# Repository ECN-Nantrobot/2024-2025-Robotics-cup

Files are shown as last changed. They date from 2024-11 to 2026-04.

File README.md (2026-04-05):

# 🤖 2025 Eurobot France Robot from EC NATES Team

<p align="center">
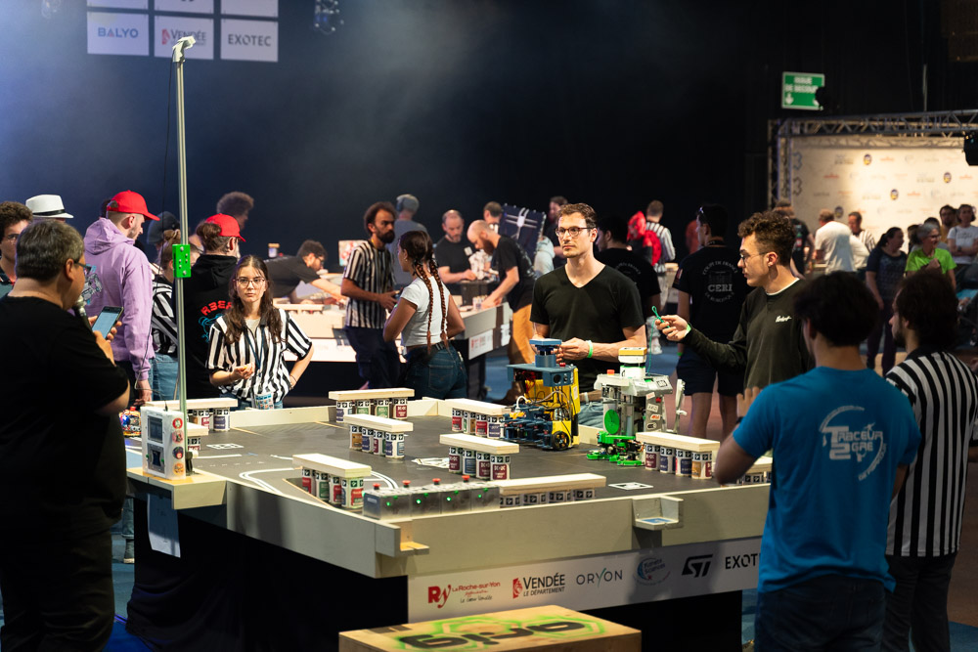
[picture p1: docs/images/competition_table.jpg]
Eurobot competition table

</p>

This repository contains the software used for our **Eurobot France 2025** mobile robot.

Competition objective (software side):
- move safely on the table,
- pick up cans,
- move them to scoring zones,
- and stack them with a wooden plank,
while coordinating high-level autonomy (Raspberry Pi + ROS2) and low-level actuation (ESP32).

---

## ⚡ Quick Summary (TL;DR)

- This repository is the full competition software stack for our **Eurobot France 2025** robot, split between high-level **ROS2** autonomy on the **Raspberry Pi** and real-time actuator control on the **ESP32**.
- The robot mission flow is: navigate the table, pick cans, transport them, and stack them according to ordered match goals defined in YAML strategies (blue/yellow team variants).
- On the ROS2 side, `main_node` coordinates mission sequencing, ESP synchronization, and runtime state progression, while `laser_to_pointcloud_node` converts LiDAR scans into map-frame pointcloud data.
- Perception updates an OpenCV-backed maze/occupancy representation; close LiDAR points are used for collision-aware behavior and safety reactions during execution.
- The planning stack includes A* path search and Elastic Band smoothing/optimization modules to turn discrete routes into smoother, obstacle-aware motion references.
- Raspberry Pi and ESP32 communicate over serial (`/dev/esp32`) with command/ack/state messages so high-level decisions and low-level actions stay synchronized.
- Deployment supports both manual ROS launching and automatic startup with `one_go.service`; additional operator setup/troubleshooting notes are collected in `noted.md`.
- The detailed sections below explain architecture layers, data flow, planning internals, state-machine behavior, build/run steps, and autostart operations.

---

## 🎥 Competition links

- **YouTube live stream (competition):** https://www.youtube.com/watch?v=Y8KNj2Q6Nss
- **Official Eurobot 2025 page:** https://www.eurobot.org/eurobot-contest/eurobot-2025/

---

## Photos

<p align="center">
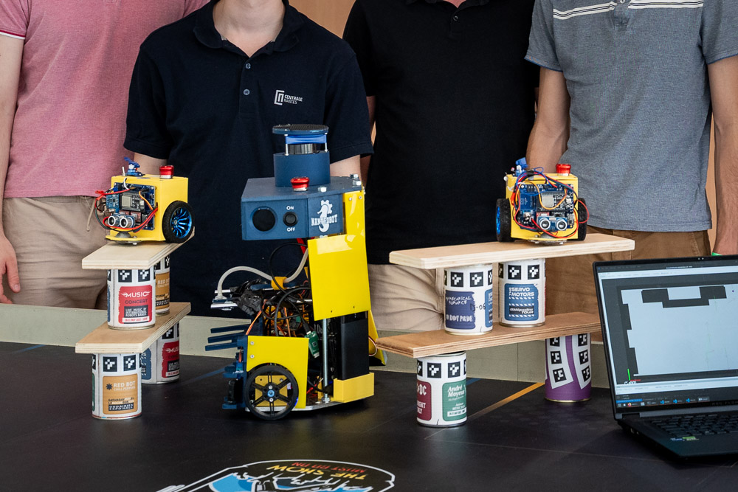
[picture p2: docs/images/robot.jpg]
Team with robot at competition
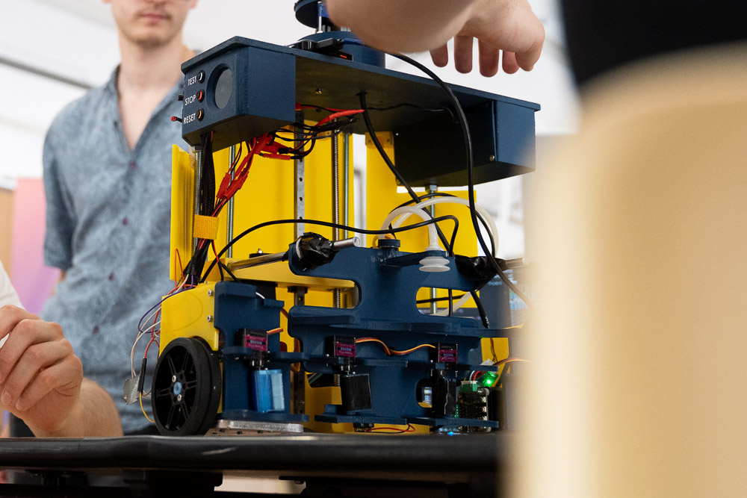
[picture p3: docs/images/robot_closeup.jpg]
Robot close-up
   
  <br>
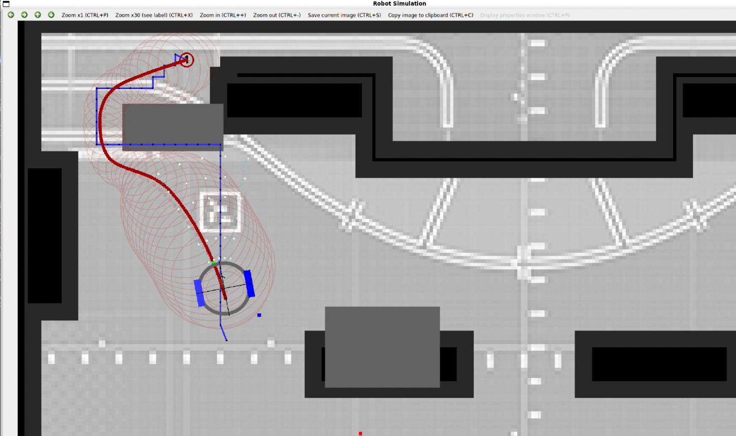
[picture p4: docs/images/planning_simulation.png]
Planning and simulation view
  
</p>

---

## 1) System architecture (code architecture, not just file tree)

The software is designed as a **layered robotics stack**.

## 🎯 Layer A — Match strategy and mission sequencing (ROS2)
Responsibility 📌:
- load team strategy (blue/yellow),
- keep an ordered goal list,
- advance mission state machine,
- synchronize with ESP (start/reset/ack/state).

Core behavior ⚡:
- `main_node` loads YAML goals and robot tuning parameters.
- It sends high-level goals and PID/speed values over serial.
- It tracks progress and decides when to move to the next objective.

---

## Layer B — Environment modeling and local world update (ROS2 + OpenCV + PointCloud)
Responsibility 📌:
- convert raw LiDAR scans into useful obstacle information,
- maintain occupancy/maze image representation,
- mark dangerous/blocked regions around detected clusters.

Core behavior ⚡:
1. LiDAR `/scan` is projected to PointCloud2 and transformed into map frame.
2. Point cloud is filtered and clustered.
3. Cluster centers are smoothed over time.
4. Circular obstacle areas are written into the map image (OpenCV-backed maze).

This is what gives the planner a live, robot-centric table understanding.

---

## Layer C — Path planning and path shaping (A* + Elastic Bands)
Responsibility 📌:
- compute traversable path from robot to current goal,
- refine the path for smooth and obstacle-aware motion.

### A* planner (global/discrete path)
- The codebase includes a generic templated **A\*** implementation.
- It builds a search tree with open/closed sets and returns an ordered path.
- Utility functions exist to save/load A* paths for debugging.

### Elastic Bands optimizer (path smoothing/optimization)
- The codebase also contains an **Elastic Band** optimizer:
  - path resampling (`resizePath`),
  - spring force term (path smoothness),
  - repulsive force term (obstacle clearance),
  - corridor checks and obstacle repulsion,
  - Gaussian smoothing for final trajectory quality.
- It queries obstacle distance using the maze distance transform for fast collision pressure.

> Important: in the current `main.cpp`, parts of A* and Elastic Band usage are present but some calls are commented while mission logic still runs via goal sequencing and safety/obstacle updates.

---

## Layer D — Motion command bridging (ROS2 ↔ ESP32 serial protocol)
Responsibility 📌:
- convert ROS-level goals/tuning into compact serial commands,
- receive acknowledgements and finite state updates from ESP.

Core behavior ⚡:
- ROS sends messages such as:
  - `GOALS:...`
  - speed/PID command payloads,
- ROS parses incoming messages such as:
  - `ACK:...`
  - `RESET`
  - state updates.

This bridge is the contract between navigation intelligence and hardware execution.

Communication behavior in practice:
- The Raspberry Pi opens the ESP link on `/dev/esp32` and waits for startup synchronization.
- During startup, ROS waits for trigger/state messages (including start/team-color flow) before mission execution.
- ROS then sends:
  - speed and PID tuning,
  - the ordered mission goals,
  - additional control messages tied to match progress.
- ESP acknowledges received commands and reports current execution state back.
- If ROS receives a reset/state change, the mission controller in `main_node` can re-initialize and safely re-sync.

---

## Layer E — Real-time low-level control (ESP32 firmware)
Responsibility 📌:
- deterministic wheel/servo/pump/stacking control,
- panel/safety handling,
- sensor and actuator timing not suitable for Linux user-space jitter.

Core behavior ⚡:
- Execute movement primitives and mechanism sequences.
- Handle pickup/stacking actions.
- Return status to ROS so high-level state machine can continue.

---

## Layer F — Launch/runtime orchestration
Responsibility 📌:
- bring up the complete runtime graph reliably.

Core behavior ⚡:
- ROS launch starts TF/static transform, robot state publisher, LiDAR driver, pointcloud transform, and main autonomy node.
- systemd service can autostart all of this on Raspberry Pi boot.

---

## 🔄 2) Data flow between components

End-to-end loop:
1. **LiDAR driver** publishes `/scan`.
2. **`laser_to_pointcloud_node`** transforms to `/pointcloud` in map frame.
3. **`main_node`** updates the OpenCV maze from clustered points.
4. **LiDAR-based collision detection** marks too-close obstacle points and can trigger emergency/safety behavior in the control loop.
5. Planner/mission logic chooses next movement objective.
6. ROS sends goal/tuning messages to ESP32 via serial (`/dev/esp32`).
7. ESP32 executes motors/servos/pump/stacking and reports state.
8. ROS advances mission state and repeats until final objective.

---

## 🧠 3) ROS2 package functionality details (`robonav`)

### 3.1 Main autonomy node
`main_node` integrates:
- serial handshake with ESP,
- team color + start synchronization,
- loading strategy YAML (`goals_blue_final.yaml` / `goals_yellow_final.yaml`),
- publication of odom/path/goals visualization topics,
- pointcloud-based obstacle map updates,
- LiDAR-based close-obstacle filtering for emergency/collision-aware behavior,
- mission progression logic.

State-machine perspective of the main loop:
- **Init / sync state**: open serial, wait for ESP availability, wait for START + team-color context.
- **Configuration state**: load YAML strategy, apply speed/PID, send goals and config payloads to ESP.
- **Run state**: execute mission step-by-step while continuously processing LiDAR-derived obstacle updates.
- **Transition state**: when a goal/action is completed and acknowledged, advance to next strategic step.
- **Safety/reset state**: if reset/emergency conditions are detected, stop or reinitialize and return to a safe synchronization phase.

This state-machine behavior is what coordinates high-level ROS mission logic with low-level ESP execution confirmations.

### 3.2 LiDAR transform node
`laser_to_pointcloud_node`:
- subscribes to `/scan`,
- projects scan to PointCloud2,
- transforms cloud into map frame via TF2,
- publishes `/pointcloud` for planning/perception pipeline.

### 3.3 Map model with OpenCV (`Maze`)
The Maze abstraction provides:
- occupancy image manipulation,
- obstacle rendering (with borders/safety margins),
- precomputed distance transform,
- fast `getDistanceToObstacle()` lookup used by path optimization forces.

This OpenCV map is central to both collision logic and path quality.

### 3.4 A* planning module
The A* module supports:
- reusable generic node-based search,
- heuristic + g/f cost handling,
- parent tree reconstruction of final path,
- optional path persistence to files for debugging and replay.

### 3.5 Elastic Bands module
The Elastic Band module supports:
- iterative path optimization,
- spring/repulsive forces,
- adaptive spacing and corridor correction,
- smoothing using Gaussian kernel,
- optional visualization utilities.

Use case:
- A* gives a valid path,
- Elastic Band transforms it into smoother, safer motion references.

### 3.6 Strategy and configuration
Competition behavior is configured through YAML:
- wheel geometry,
- speed/PID defaults,
- ordered goals for each team color,
- obstacle templates.

---

## ⚙️ 4) ESP32 firmware functionality (control architecture)

The ESP firmware acts as a **real-time execution controller**.

Major functional blocks:
- drivetrain motion control,
- servo control,
- pump control,
- stacking sequence management,
- power monitoring,
- control panel / emergency and safety handling,
- command parser for ROS serial protocol.

Design intent:
- ROS does “what to do next”,
- ESP does “how to move and actuate now”.

---

## 🛠️ 5) Technologies used

### Raspberry Pi / ROS side
- ROS 2 Humble
- C++17
- Python ROS launch
- OpenCV (map and image operations)
- PCL + laser_geometry + TF2 (pointcloud and transforms)
- yaml-cpp (strategy/config loading)
- systemd (autostart)

### ESP side
- PlatformIO
- Arduino framework (ESP32)
- AccelStepper, ContinuousStepper, TFT_eSPI, INA219, PWM servo driver

---

## ⏱️ 6) Runtime sequence during a match

1. Boot RPi and ESP.
2. Launch ROS graph (manual or systemd).
3. Wait for ESP start/team-color synchronization.
4. Load corresponding team goals.
5. Start mission loop:
   - perceive obstacles,
   - update map,
   - plan/shape motion,
   - send commands,
   - execute pickup/stacking actions,
   - verify state and continue.
6. End at final strategic goal.

---

## 🚀 7) Build and run

### 🧪 ROS2 workspace (RPi)
```bash
colcon build --symlink-install
source install/setup.bash
ros2 launch robonav launch.launch.py
```

### 🔋 ESP firmware
- Open `Firmware/` with PlatformIO.
- Build and upload to ESP32.
- Ensure serial mapping is correct (`/dev/esp32` expected on RPi side).

---

## 🔁 8) Autostart (RPi)
Use the provided service assets to launch on boot:
- `src/robonav/autostart/one_go.sh`
- `src/robonav/autostart/one_go.service`

Then monitor:
```bash
journalctl -u one_go.service -f
```

---

## 📝 9) Practical operations notes

- Always confirm team color strategy file before match.
- Validate LiDAR and ESP serial devices after reboot.
- Keep ROS and firmware commits synchronized.
- Perform full mechanism test (pickup/stacking) before table deployment.

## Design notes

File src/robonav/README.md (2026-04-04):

# make it executable
chmod +x /home/pi/2024-2025-Robotics-cup/auto_start/one_go.sh

# make one_go.service symbolic so that you can call one_go.service with systemctl
sudo ln -s /home/pi/2024-2025-Robotics-cup/auto_start/one_go.service /etc/systemd/system

# enable and start one_go.service
sudo systemctl daemon-reload
sudo systemctl enable one_go.service
sudo systemctl start one_go.service
# now the launch will be start when the robot boots

# check if it's running
systemctl status one_go.service

Delete the service:
sudo systemctl stop one_go.service
sudo systemctl disable one_go.service
sudo rm /etc/systemd/system/one_go.service
sudo systemctl daemon-reload

# Live Logs output:
journalctl -u one_go.service -f

# Wifi: 
cd /etc/netplan/50-cloud-init.yaml
sudo netplan apply

# Launch Ros2
colcon build --symlink-install      in the 2024-2025..... 
source install/setup.bash
ros2 launch robonav launch.launch.py

ros2 run robonav led_test_node

I also made a file to auto detect the lidar and esp automatically and map the ports to /dev/esp32 and /dev/rplidar, so you can set teh port in platform.io extension to /dev/esp32

Safe start button needs to be on reset to upload, and press reset while it is building because sometimes it doesnt upload properly, and emergency need to be pressed

Starting and resetting the RPI takes a little bit long, I dont know, maybe because of the LED fucntion but not sure

The RPI Led is on GPIO pin 16

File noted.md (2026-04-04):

# Robot Operations Notes (Raspberry Pi + ROS2 + ESP32)

This file keeps practical setup and troubleshooting notes for running the robot on the Raspberry Pi.

---

## 1) Make autostart script executable

```bash
chmod +x /home/pi/2024-2025-Robotics-cup/auto_start/one_go.sh
```

---

## 2) Register `one_go.service` with systemd

Create a symbolic link so `systemctl` can manage the service:

```bash
sudo ln -s /home/pi/2024-2025-Robotics-cup/auto_start/one_go.service /etc/systemd/system
```

---

## 3) Enable and start service at boot

```bash
sudo systemctl daemon-reload
sudo systemctl enable one_go.service
sudo systemctl start one_go.service
```

After this, launch should start automatically when the robot boots.

Check status:

```bash
systemctl status one_go.service
```

---

## 4) Delete/remove the service

```bash
sudo systemctl stop one_go.service
sudo systemctl disable one_go.service
sudo rm /etc/systemd/system/one_go.service
sudo systemctl daemon-reload
```

---

## 5) Live logs

```bash
journalctl -u one_go.service -f
```

---

## 6) Wi-Fi/netplan

```bash
cd /etc/netplan/50-cloud-init.yaml
sudo netplan apply
```

---

## 7) Launch ROS2 manually

From repository root (`2024-2025-Robotics-cup`):

```bash
colcon build --symlink-install
source install/setup.bash
ros2 launch robonav launch.launch.py
```

Test node:

```bash
ros2 run robonav led_test_node
```

---

## 8) Device mapping note

A helper file/rule is used to auto-detect LiDAR and ESP and map ports to:
- `/dev/esp32`
- `/dev/rplidar`

In PlatformIO, you can set upload/monitor port to `/dev/esp32`.

---

## 9) ESP upload notes

- Keep **Safe Start button** on reset for upload.
- Press **reset while building/uploading** if upload fails (this happens sometimes).
- Emergency button needs to be pressed.

---

## 10) Startup/reset behavior note

- Raspberry Pi startup/reset can be a bit slow.
- Possible reason might be LED-related behavior (not confirmed).

Raspberry Pi LED pin used in this project:
- **GPIO 16**

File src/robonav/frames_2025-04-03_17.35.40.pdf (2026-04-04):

view_frames Result

Recorded at time: 1743701740.3750396

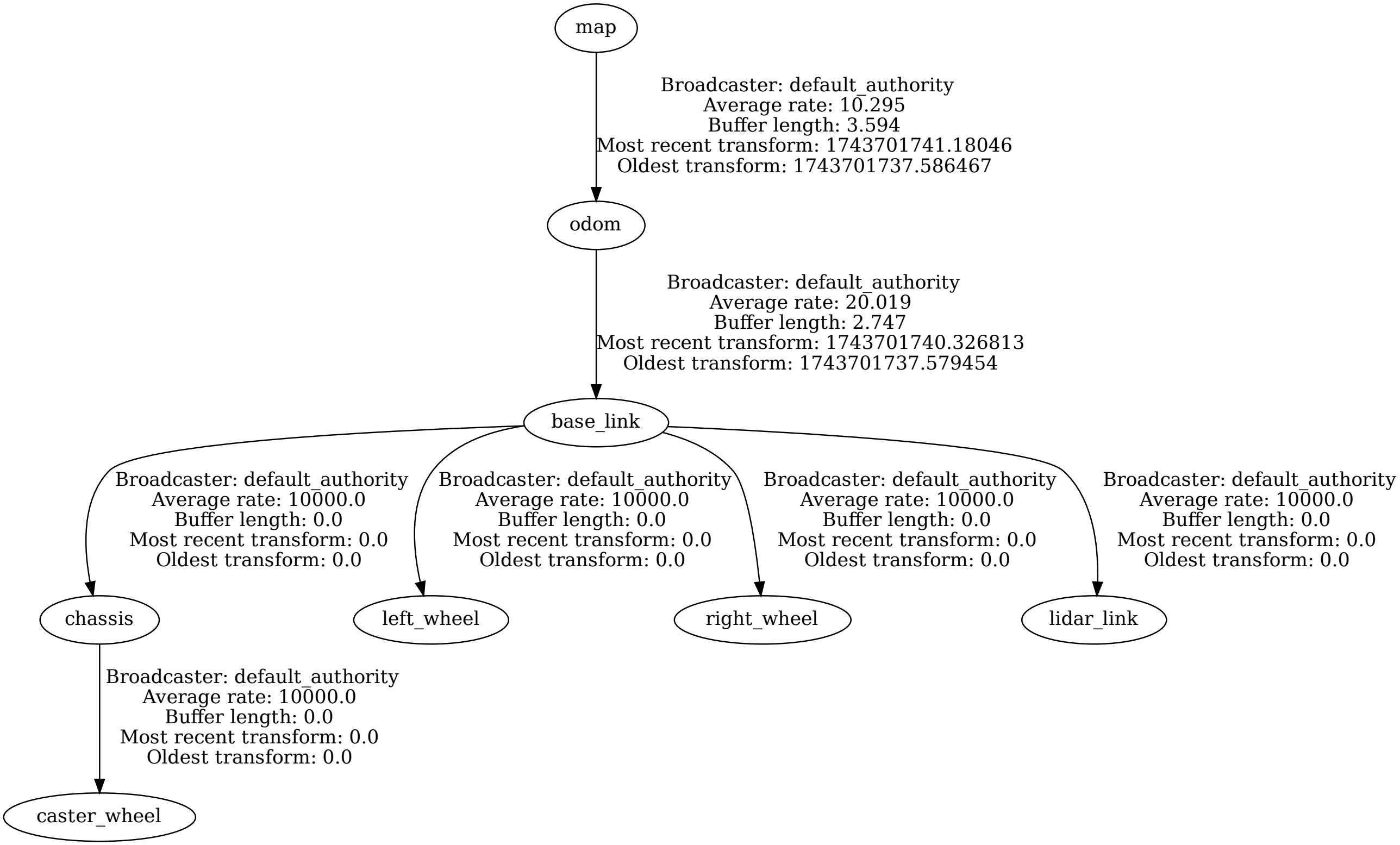
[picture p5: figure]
chassis; caster_wheel; Broadcaster: default_authority Average rate: 10000.0 Buffer length: 0.0 Most recent transform: 0.0 Oldest transform: 0.0; base_link; left_wheel; right_wheel; lidar_link; odom; Broadcaster: default_authority Average rate: 20.019 Buffer length: 2.747 Most recent transform: 1743701740.326813 Oldest transform: 1743701737.579454; map; Broadcaster: default_authority Average rate: 10.295 Buffer length: 3.594 Most recent transform: 1743701741.18046 Oldest transform: 1743701737.586467

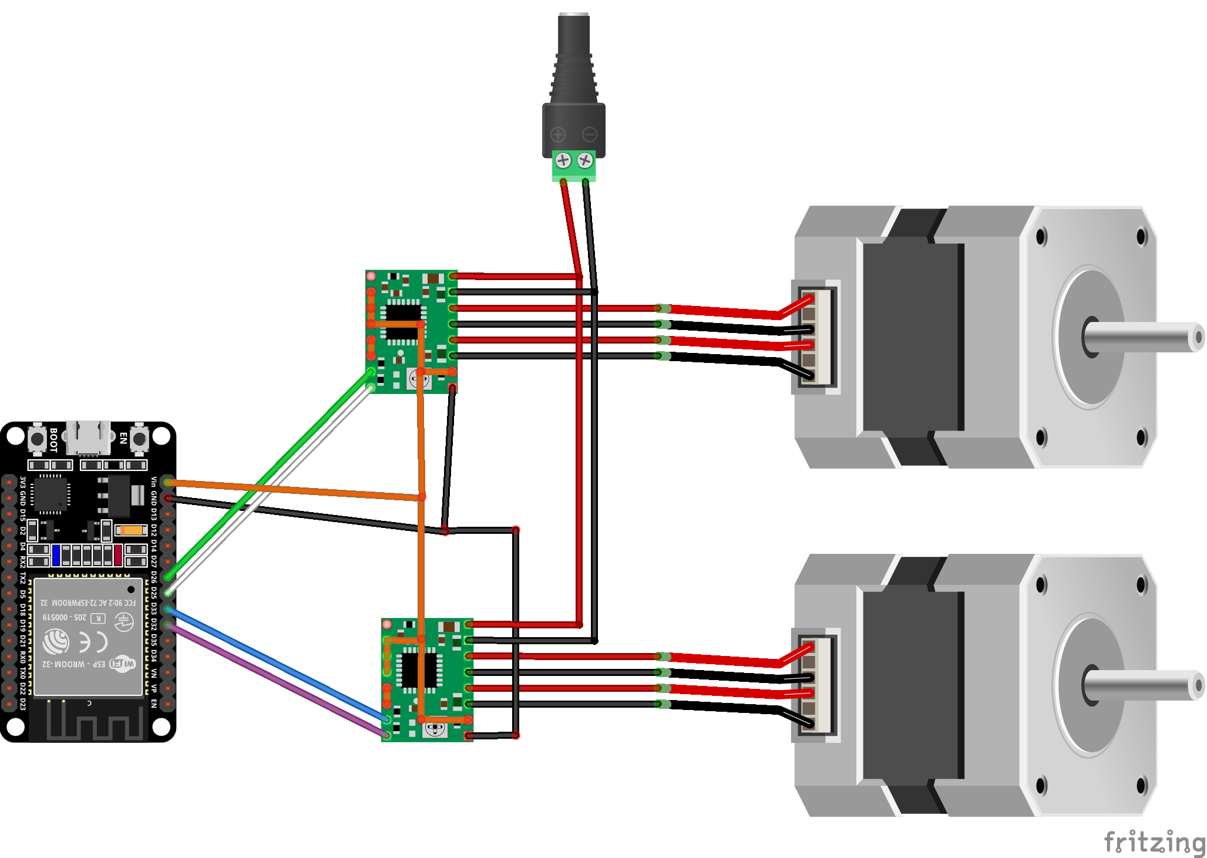
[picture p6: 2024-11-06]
Individual test/Mobile base/schematics esp32 2xNema17_bb.png

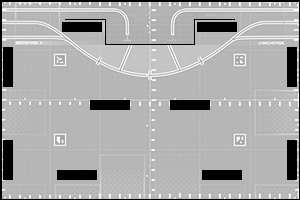
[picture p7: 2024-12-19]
src/robonav/maps/Eurobot_map_real_bw_10_p.png

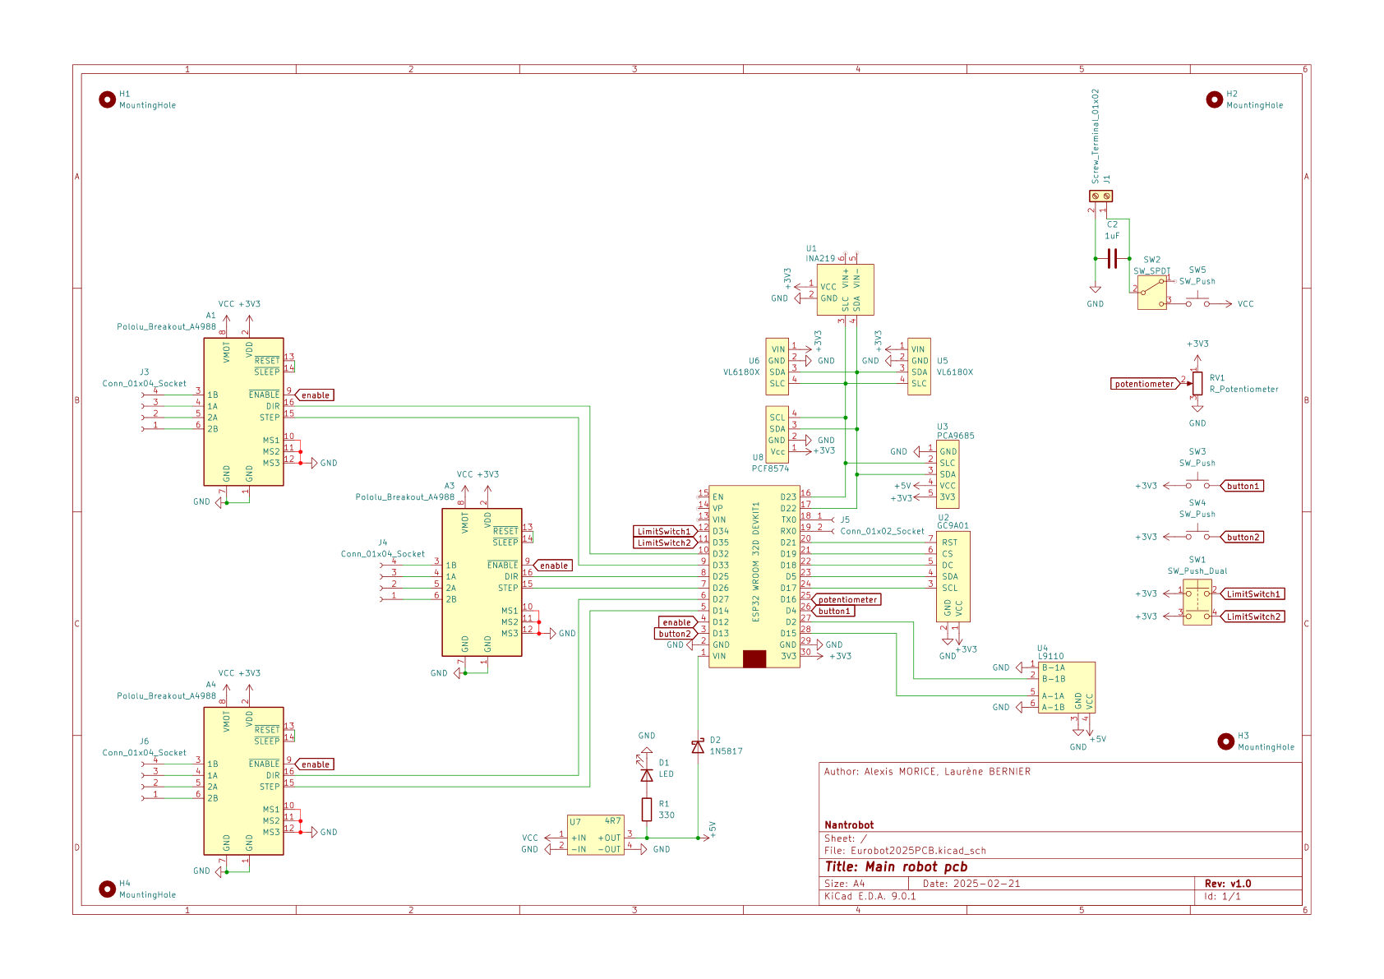
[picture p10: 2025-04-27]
Electrical/Version 2.0.png

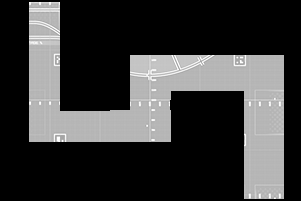
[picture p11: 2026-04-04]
src/robonav/maps/Eurobot_map_real_bw_10_p_interact.png

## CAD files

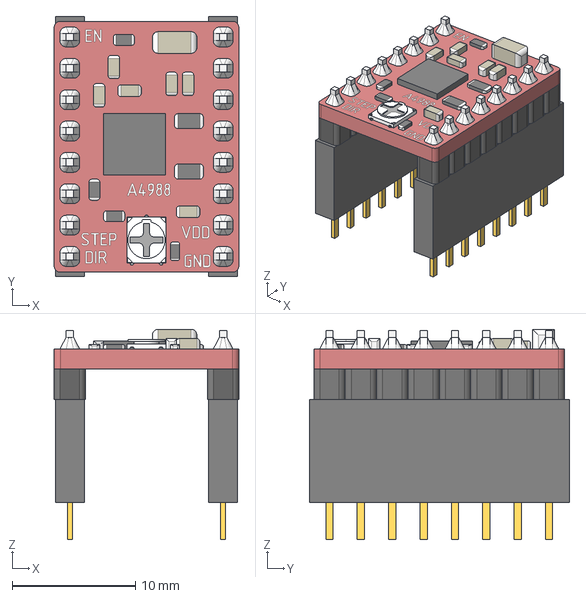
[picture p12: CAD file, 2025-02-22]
Electrical/Eurobot2025PCB/3D/A4988-Stepper-Driver-Socketed.stp
15.0 x 21.1 x 17.1 mm

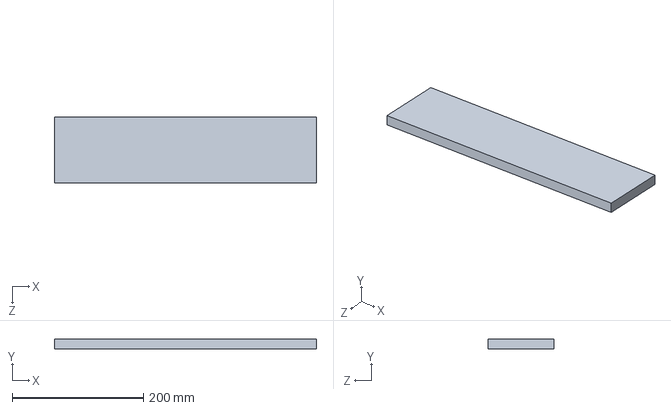
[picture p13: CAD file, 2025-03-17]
Mecanical/CAD/GAME ELEMENT/WOOD_PLATFORM.SLDPRT
400.0 x 15.0 x 100.0 mm

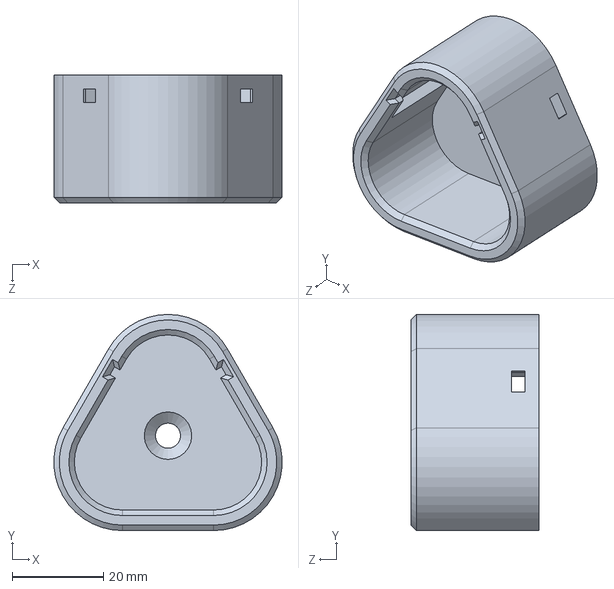
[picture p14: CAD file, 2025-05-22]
Mecanical/CAD/MOBILE BASE/BATTERY_HOLDER.SLDPRT
49.9 x 47.3 x 28.0 mm

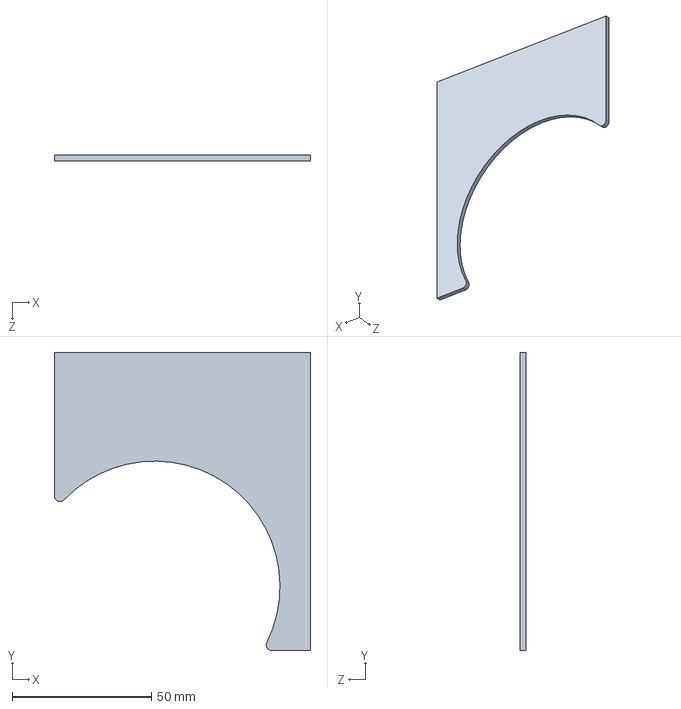
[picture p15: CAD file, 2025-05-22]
Mecanical/CAD/MOBILE BASE/Carter/motor_panel.SLDPRT
92.0 x 107.0 x 2.00 mm

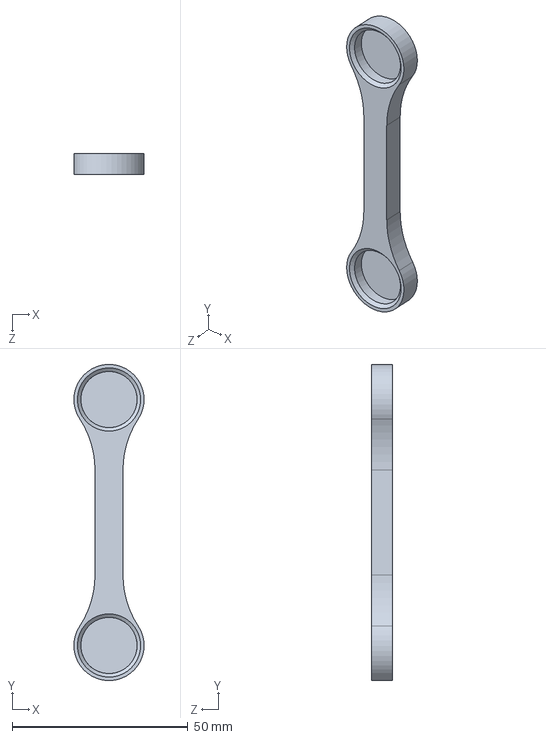
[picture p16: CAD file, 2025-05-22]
Mecanical/CAD/STACKING/Arm2.SLDPRT
20.0 x 89.9 x 6.00 mm

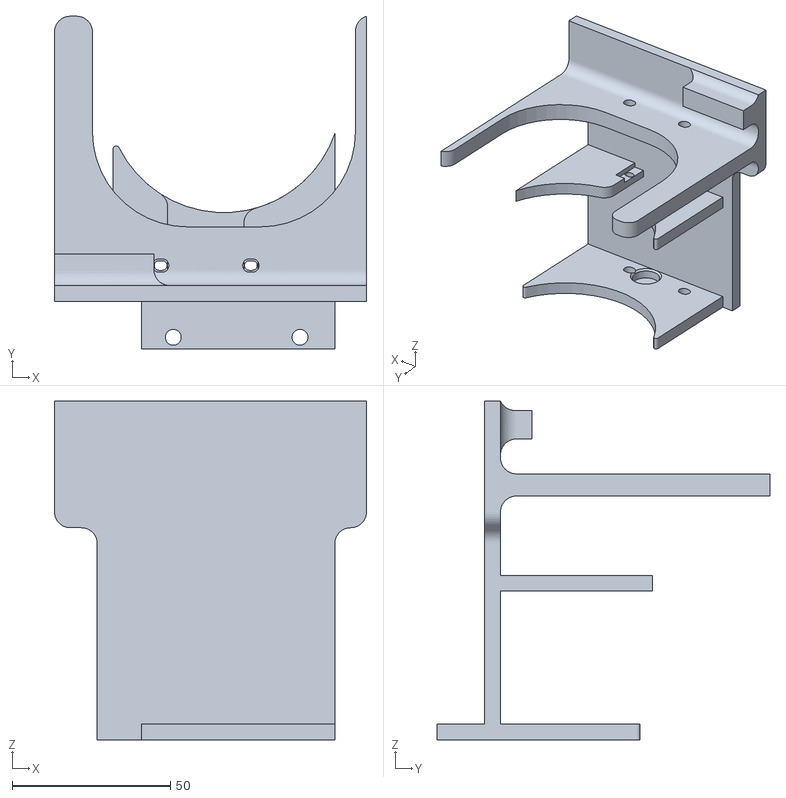
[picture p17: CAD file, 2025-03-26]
Mecanical/FRONT_ACTUATOR_SIDE.STL
98.5 x 105.0 x 107.0

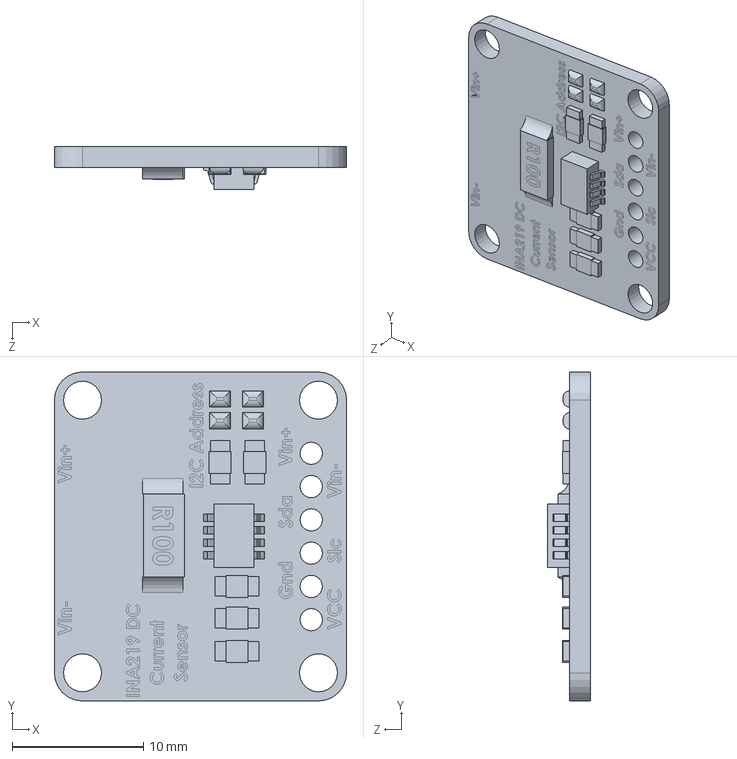
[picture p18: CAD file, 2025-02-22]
Electrical/Eurobot2025PCB/3D/INA219.SLDPRT
22.3 x 25.1 x 3.30 mm

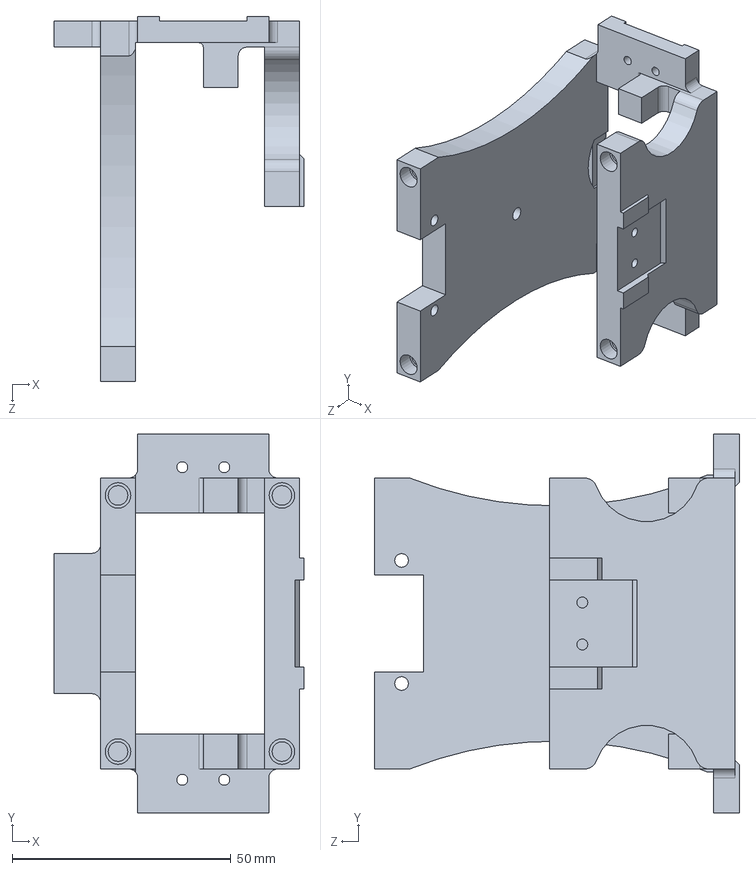
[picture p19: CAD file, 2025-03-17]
Mecanical/CAD/BANNER/MOVING_FRAME.SLDPRT
57.1 x 86.6 x 83.5 mm

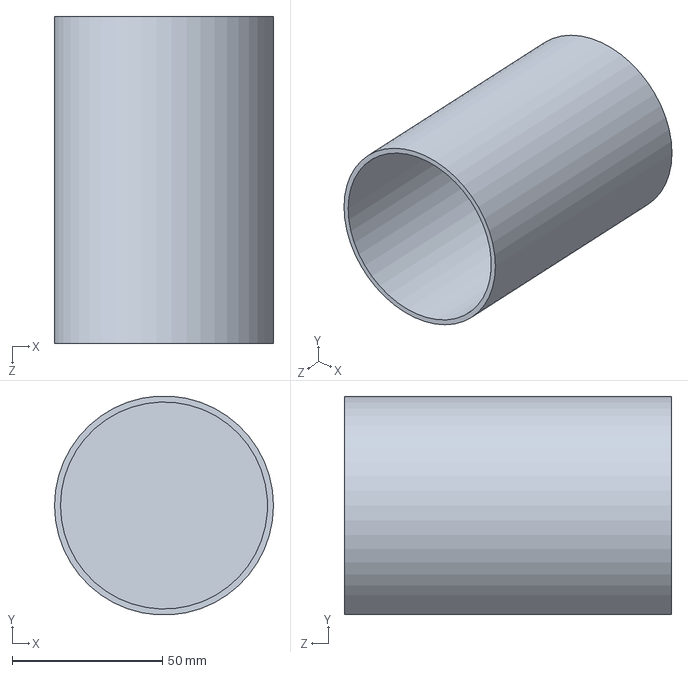
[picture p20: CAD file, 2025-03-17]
Mecanical/CAD/GAME ELEMENT/TIN_CAN.SLDPRT
73.0 x 72.8 x 109.0 mm

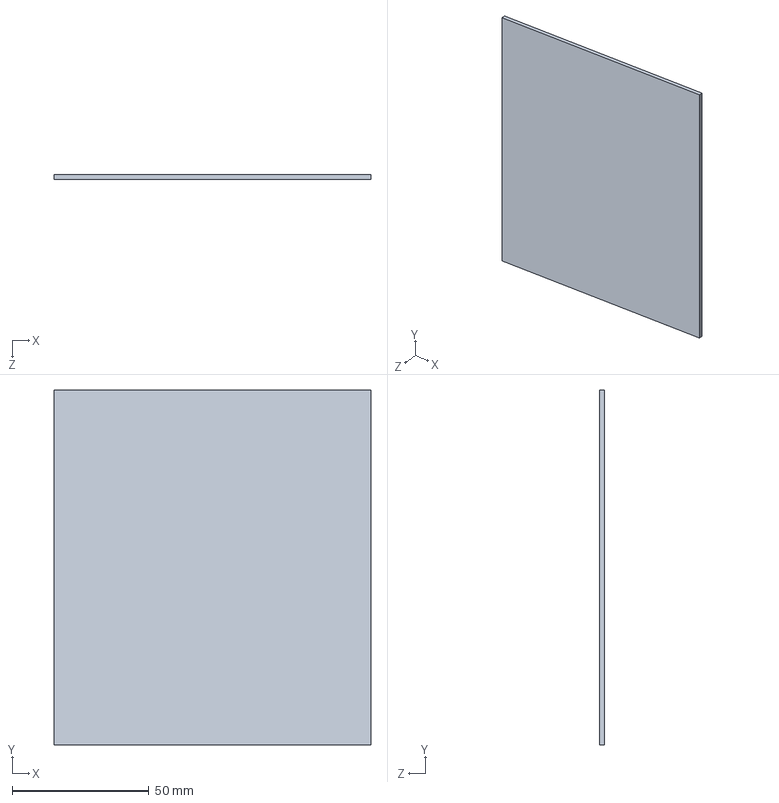
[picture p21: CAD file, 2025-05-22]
Mecanical/CAD/MOBILE BASE/Carter/diagonal_panel_bottom.SLDPRT
116.0 x 130.0 x 2.00 mm

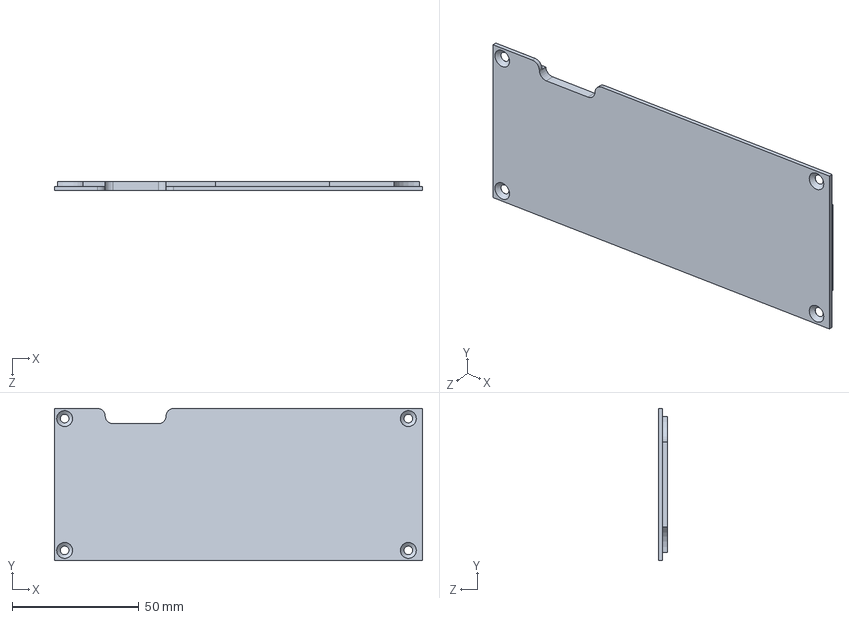
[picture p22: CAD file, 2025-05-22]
Mecanical/CAD/MOBILE BASE/Control_panel_door_estop.SLDPRT
145.1 x 60.0 x 3.50 mm

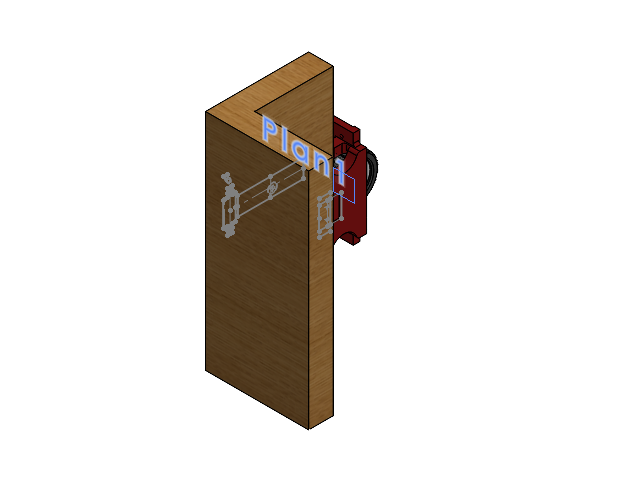
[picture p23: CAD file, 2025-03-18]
Mecanical/CAD/BANNER/MOVING_ASSEMBLY.SLDASM
Moving_frame
RIM
TIRE
DC_MOTOR
WALL
BEARING x 6

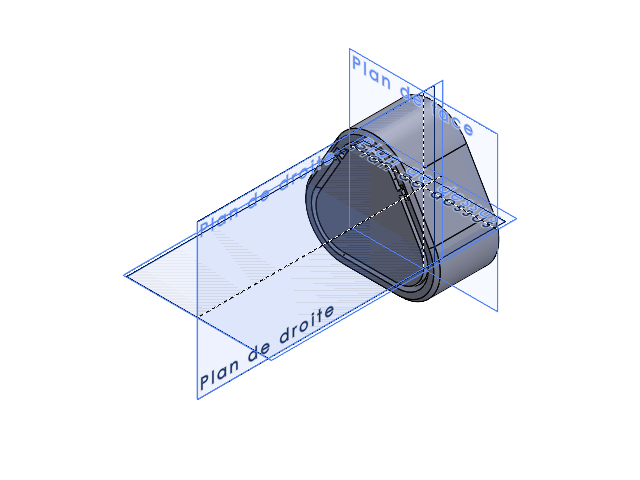
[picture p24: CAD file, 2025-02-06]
Mecanical/CAD/MOBILE BASE/Battery/BATTERY_ASSEMBLY.SLDASM
BATTERY_HOLDER
BATTERY_12V_PARKSIDE_2Ah

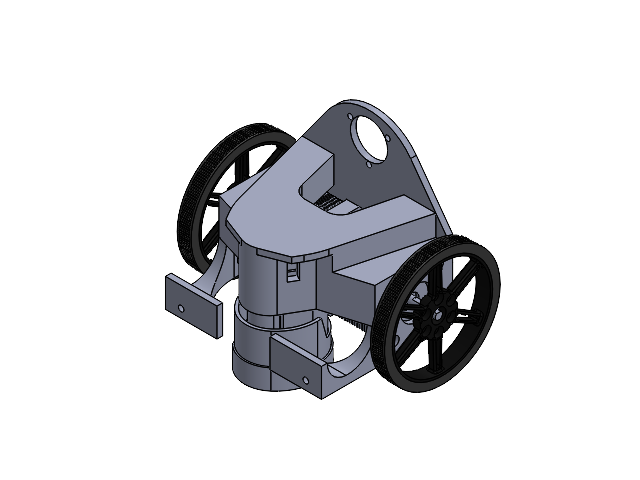
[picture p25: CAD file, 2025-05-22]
Mecanical/CAD/SIMA/SIMA.SLDASM
Base_sima
STEPPER x 2
BATTERY_12V_PARKSIDE_2Ah
WHELL_80 x 2

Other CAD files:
Mecanical/CAD/MOBILE BASE/Battery/BATTERY_ASSEMBLY2.SLDASM
Mecanical/CAD/STACKING/FRONT_ACTUATOR_TEST_FIT.SLDASM
Mecanical/CAD/STACKING/Stacking_mechanism.SLDASM
Mecanical/CAD/MOBILE BASE/Starter_test_fit.SLDASM
Mecanical/CAD/BANNER/Motor_bracket.SLDPRT
Mecanical/CAD/GAME ELEMENT/WALL.SLDPRT
Mecanical/CAD/MOBILE BASE/Base.DXF
Mecanical/CAD/MOBILE BASE/Base.SLDDRW
Mecanical/CAD/MOBILE BASE/Base.SLDPRT
Mecanical/CAD/MOBILE BASE/Battery/BATTERY_HOLDER.STL
Mecanical/CAD/MOBILE BASE/Board_holder.SLDPRT
Mecanical/CAD/MOBILE BASE/Carter/back_panel.DWG
Mecanical/CAD/MOBILE BASE/Carter/back_panel.DXF
Mecanical/CAD/MOBILE BASE/Carter/back_panel.SLDDRW
Mecanical/CAD/MOBILE BASE/Carter/back_panel.SLDPRT
Mecanical/CAD/MOBILE BASE/Carter/diagonal_panel.DWG
Mecanical/CAD/MOBILE BASE/Carter/diagonal_panel.DXF
Mecanical/CAD/MOBILE BASE/Carter/diagonal_panel.SLDDRW
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

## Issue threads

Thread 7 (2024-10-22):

Test actuator for the stacking mechanism (servos, step motor,...)

py-Alexis, 2024-10-22:

py-Alexis, 2024-10-24:
for step motor
https://lastminuteengineers.com/a4988-stepper-motor-driver-arduino-tutorial/

Closed 2025-03-17.

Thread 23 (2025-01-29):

Electronic circuit for the banner

py-Alexis, 2025-01-29:
- [ ] make the diagram for the circuit
(to include buttons to detect when placed on the edge (or when dropped) a switch to change the motor direction, emergency button)
- [ ] research which emergency button to buy
- [ ] test the circuit
- [ ] validate the termination method (corner detection or cable unplugging)
- [ ] solder the finish circuit (when CAD is finished

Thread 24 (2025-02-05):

Update moving banner mount

Zeraphu, 2025-02-05:
- [ ] Update all insert bore (outwards) so that bolts can be snug fit w/ smooth spinning deadwheel
- [ ] Update middle bores (next to driven wheel) (lower) to allow dead wheel mounting
- [ ] Add limit switch mount on inner corner side
- [ ] Add limit switch mount on inner bottom side (to detect bot hold)
- [ ] Add a single battery mount
- [ ] Change shape of outer flange to a curve - to facilitate easy loading on to the wall

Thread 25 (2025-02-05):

CAD for static banner mount

Zeraphu, 2025-02-05:
Functional reqs:
1. Internal stability on the wall & able to endure lateral forces to some extent.
2. Has a limit switch to indicate when moving banner mount hits.

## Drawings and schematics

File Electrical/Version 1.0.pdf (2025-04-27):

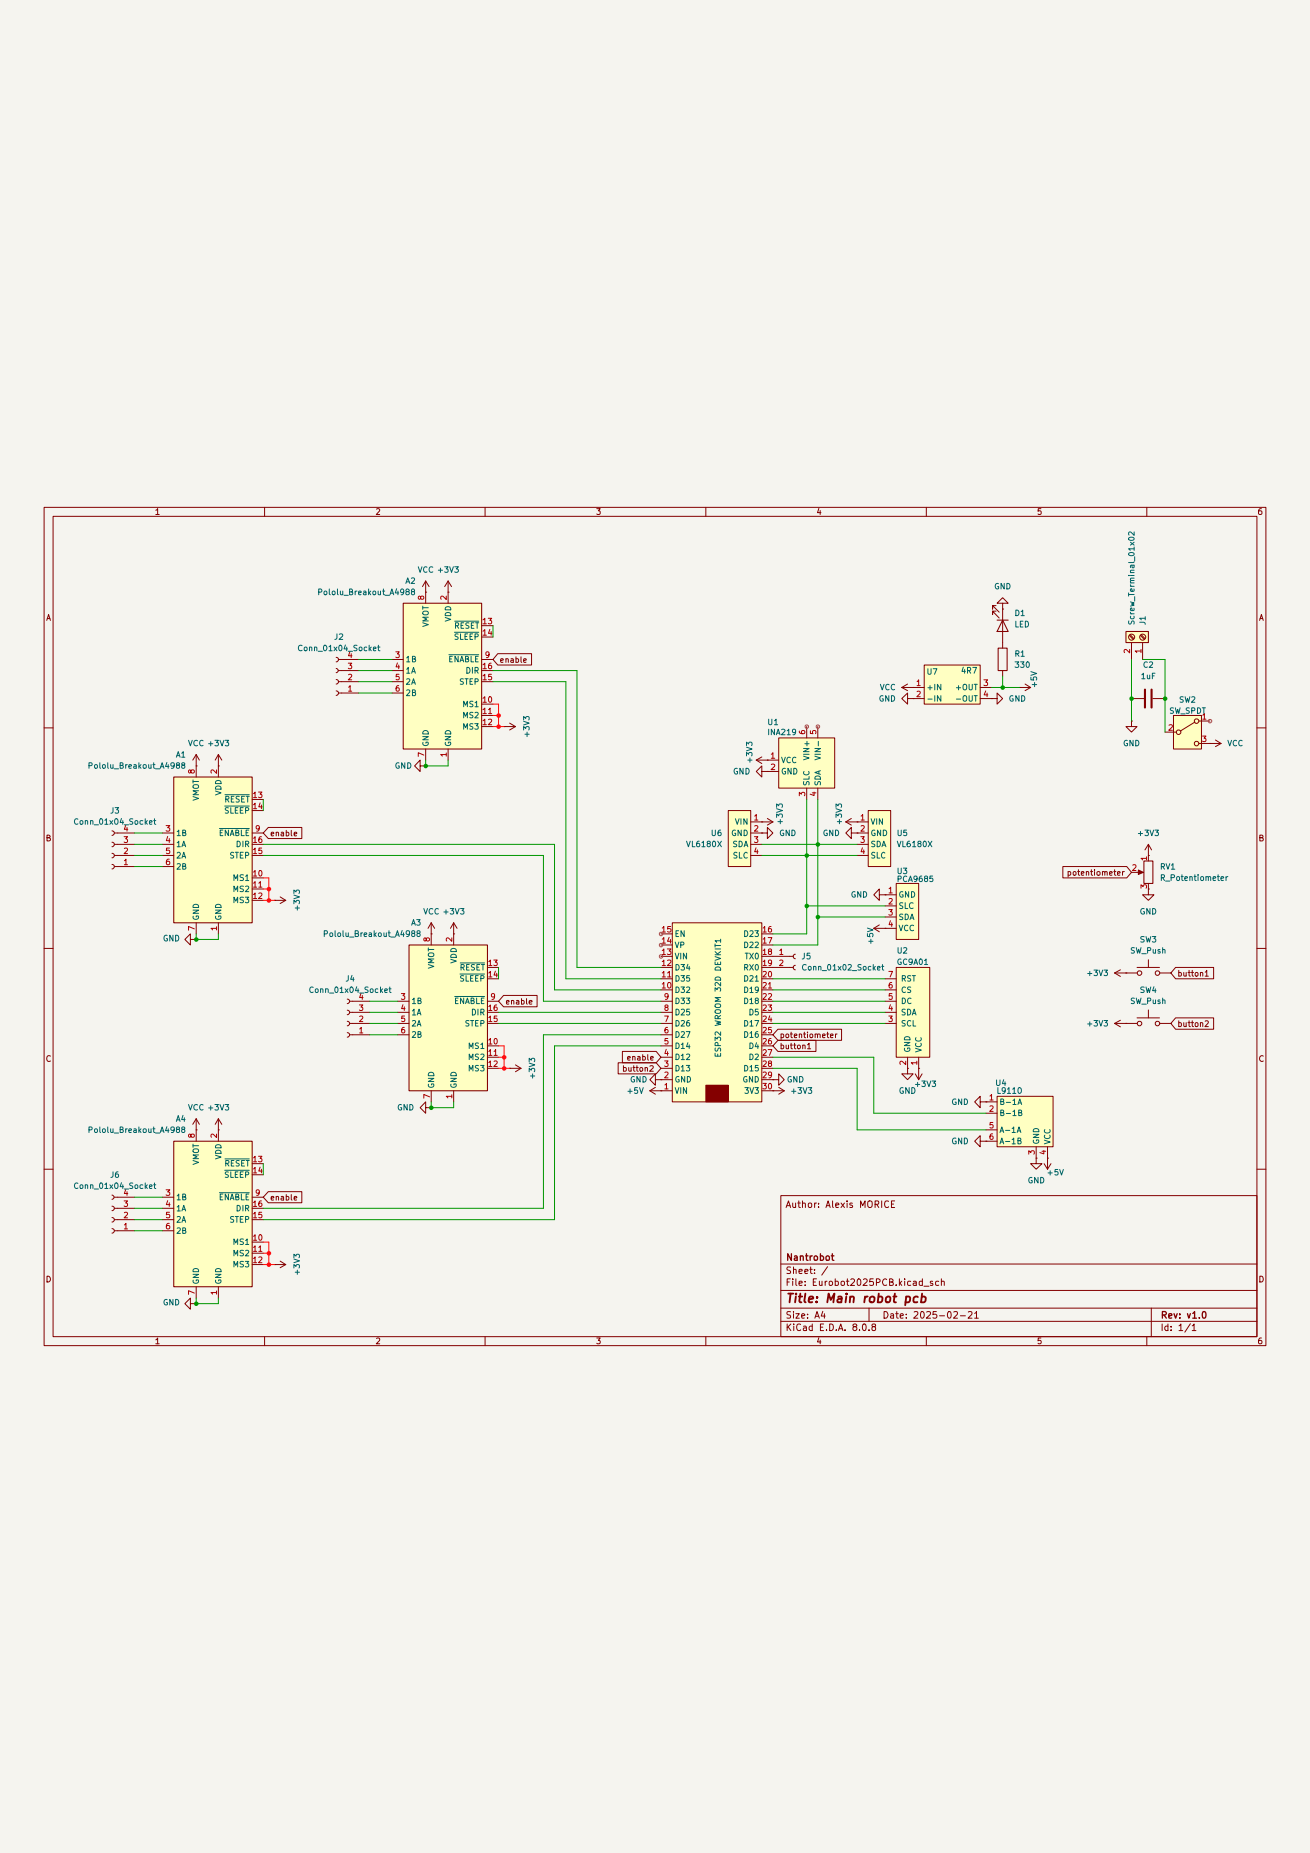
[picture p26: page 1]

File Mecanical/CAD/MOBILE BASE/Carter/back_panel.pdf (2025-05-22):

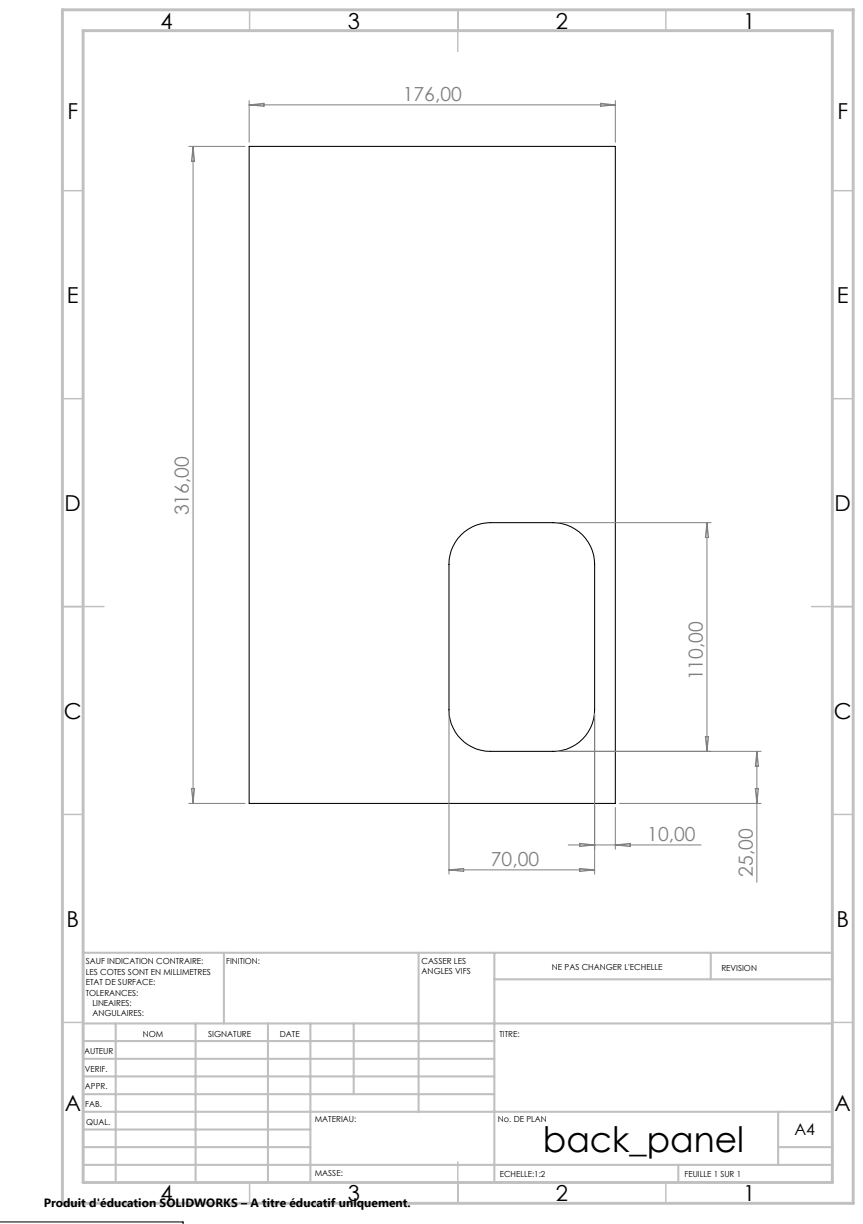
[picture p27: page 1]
FINITION:; CASSER LES; ANGLES VIFS; NE PAS CHANGER L'ECHELLE; REVISION; ECHELLE:1:2; FEUILLE 1 SUR 1

SAUF INDICATION CONTRAIRE:
LES COTES SONT EN MILLIMETRES
ETAT DE SURFACE:
TOLERANCES:
LINEAIRES:
ANGULAIRES:

NOM | SIGNATURE | DATE | | | | TITRE:

AUTEUR
VERIF.
APPR.
FAB.
QUAL. | | | | MATERIAU: | No. DE PLAN back_panel | A4

Produit d'éducation SOLIDWORKS – A titre éducatif uniquement.

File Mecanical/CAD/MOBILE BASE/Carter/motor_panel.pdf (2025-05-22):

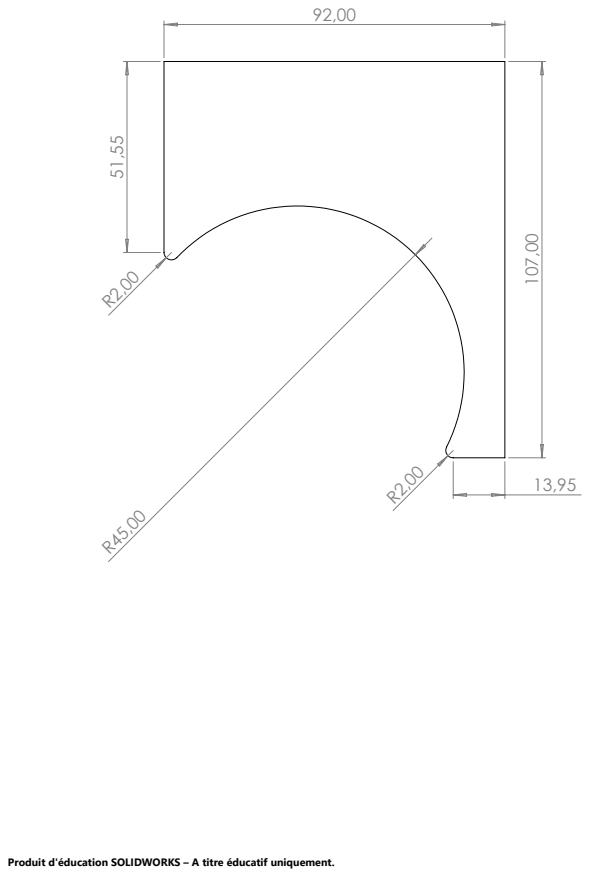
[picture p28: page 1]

Produit d'éducation SOLIDWORKS – A titre éducatif uniquement.

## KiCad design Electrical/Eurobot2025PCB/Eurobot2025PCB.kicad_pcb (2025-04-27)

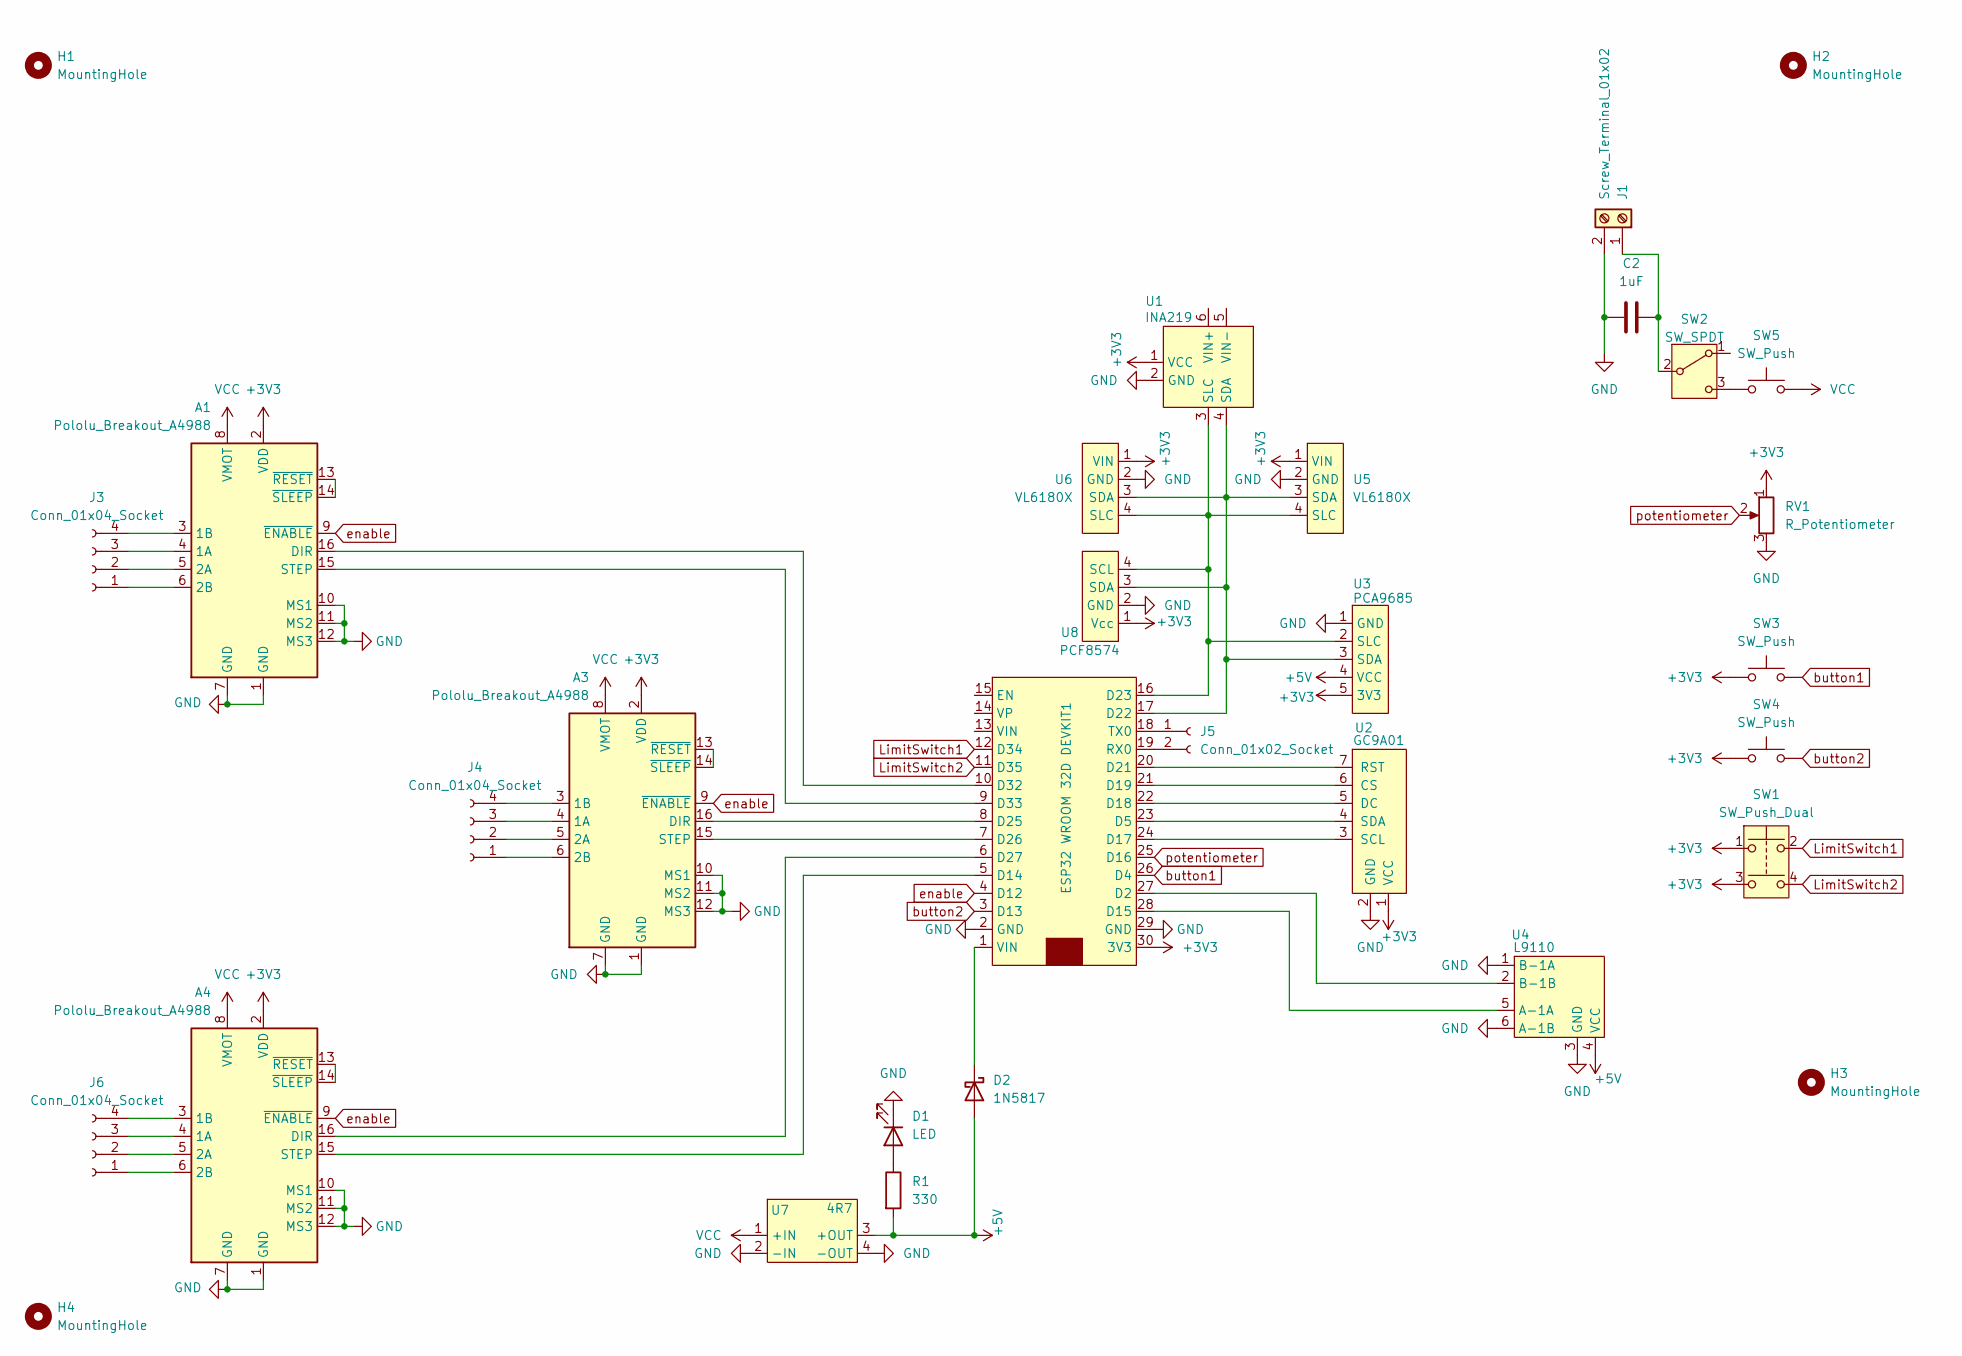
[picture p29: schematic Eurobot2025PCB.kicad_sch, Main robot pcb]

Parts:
A1, A3, A4: Pololu_Breakout_A4988; A4988
C2: 1uF; C_Radial_D5.0mm_H11.0mm_P2.00mm
D1: LED; LED_D5.0mm
D2: 1N5817; D_DO-41_SOD81_P10.16mm_Horizontal
ESP32 WROOM 32D DEVKIT1: ESP32 WROOM 32D
H1, H2, H3, H4: MountingHole; MountingHole_3.2mm_M3
J1: Screw_Terminal_01x02; TerminalBlock_MetzConnect_Type059_RT06302HBWC_1x02_P3.50mm_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
J3, J4, J6: Conn_01x04_Socket; JST_XH_B4B-XH-A_1x04_P2.50mm_Vertical
J5: Conn_01x02_Socket; PinHeader_1x02_P2.54mm_Vertical
R1: 330; R_Axial_DIN0207_L6.3mm_D2.5mm_P10.16mm_Horizontal
RV1: R_Potentiometer; PinHeader_1x03_P2.54mm_Vertical
SW1: SW_Push_Dual; PinHeader_2x02_P2.54mm_Vertical
SW2: SW_SPDT; SW_XKB_DM1-16UP-1
SW3, SW4: SW_Push; SW_PUSH_6mm
SW5: SW_Push; JST_XH_B2B-XH-A_1x02_P2.50mm_Vertical
U1: INA219; INA219 DC current sensor
U2: GC9A01; PinHeader_1x07_P2.54mm_Vertical
U3: PCA9685; PinHeader_1x05_P2.54mm_Vertical
U4: L9110
U5, U6: VL6180X; PinHeader_1x04_P2.54mm_Vertical
U7: 4R7
U8: PCF8574; PinHeader_1x04_P2.54mm_Vertical

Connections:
+3V3: A1.2 (VDD), A3.2 (VDD), A4.2 (VDD), ESP32 WROOM 32D DEVKIT1.30 (3V3), RV1.1, SW1.1, SW1.3, SW3.1, SW4.1, U1.1 (VCC), U2.1 (VCC), U3.5 (3V3), U5.1 (VIN), U6.1 (VIN), U8.1 (Vcc)
+5V: D2.2 (A), R1.2, U3.4 (VCC), U4.4 (VCC), U7.3 (+OUT)
GND: A1.1 (GND), A1.7 (GND), A1.10 (MS1), A1.11 (MS2), A1.12 (MS3), A3.1 (GND), A3.7 (GND), A3.10 (MS1), A3.11 (MS2), A3.12 (MS3), A4.1 (GND), A4.7 (GND), A4.10 (MS1), A4.11 (MS2), A4.12 (MS3), C2.1, D1.1 (K), ESP32 WROOM 32D DEVKIT1.2 (GND), ESP32 WROOM 32D DEVKIT1.29 (GND), J1.2, RV1.3, U1.2 (GND), U2.2 (GND), U3.1 (GND), U4.1 (B-1A), U4.3 (GND), U4.6 (A-1B), U5.2 (GND), U6.2 (GND), U7.2 (-IN), U7.4 (-OUT), U8.2 (GND)
LimitSwitch1: ESP32 WROOM 32D DEVKIT1.12 (D34), SW1.2
LimitSwitch2: ESP32 WROOM 32D DEVKIT1.11 (D35), SW1.4
unnamed: A1.4 (1A), J3.3
unnamed: A1.3 (1B), J3.4
unnamed: A1.5 (2A), J3.2
unnamed: A1.6 (2B), J3.1
unnamed: A1.16 (DIR), ESP32 WROOM 32D DEVKIT1.10 (D32)
unnamed: A1.15 (STEP), ESP32 WROOM 32D DEVKIT1.9 (D33)
unnamed: A1.13 (~RESET), A1.14 (~SLEEP)
unnamed: A3.4 (1A), J4.3
unnamed: A3.3 (1B), J4.4
unnamed: A3.5 (2A), J4.2
unnamed: A3.6 (2B), J4.1
unnamed: A3.16 (DIR), ESP32 WROOM 32D DEVKIT1.8 (D25)
unnamed: A3.15 (STEP), ESP32 WROOM 32D DEVKIT1.7 (D26)
unnamed: A3.13 (~RESET), A3.14 (~SLEEP)
unnamed: A4.4 (1A), J6.3
unnamed: A4.3 (1B), J6.4
unnamed: A4.5 (2A), J6.2
unnamed: A4.6 (2B), J6.1
unnamed: A4.16 (DIR), ESP32 WROOM 32D DEVKIT1.6 (D27)
unnamed: A4.15 (STEP), ESP32 WROOM 32D DEVKIT1.5 (D14)
unnamed: A4.13 (~RESET), A4.14 (~SLEEP)
unnamed: D1.2 (A), R1.1
unnamed: D2.1 (K), ESP32 WROOM 32D DEVKIT1.1 (VIN)
unnamed: ESP32 WROOM 32D DEVKIT1.27 (D2), U4.2 (B-1B)
unnamed: ESP32 WROOM 32D DEVKIT1.23 (D5), U2.4 (SDA)
unnamed: ESP32 WROOM 32D DEVKIT1.28 (D15), U4.5 (A-1A)
unnamed: ESP32 WROOM 32D DEVKIT1.24 (D17), U2.3 (SCL)
unnamed: ESP32 WROOM 32D DEVKIT1.22 (D18), U2.5 (DC)
unnamed: ESP32 WROOM 32D DEVKIT1.21 (D19), U2.6 (CS)
unnamed: ESP32 WROOM 32D DEVKIT1.20 (D21), U2.7 (RST)
unnamed: ESP32 WROOM 32D DEVKIT1.17 (D22), U1.4 (SDA), U3.3 (SDA), U5.3 (SDA), U6.3 (SDA), U8.3 (SDA)
unnamed: ESP32 WROOM 32D DEVKIT1.16 (D23), U1.3 (SLC), U3.2 (SLC), U5.4 (SLC), U6.4 (SLC), U8.4 (SCL)
unnamed: ESP32 WROOM 32D DEVKIT1.19 (RX0), J5.2
unnamed: ESP32 WROOM 32D DEVKIT1.18 (TX0), J5.1
unnamed: C2.2, J1.1, SW2.2 (B)
unnamed: SW2.3 (C), SW5.1
VCC: A1.8 (VMOT), A3.8 (VMOT), A4.8 (VMOT), SW5.2, U7.1 (+IN)
button1: ESP32 WROOM 32D DEVKIT1.26 (D4), SW3.2
button2: ESP32 WROOM 32D DEVKIT1.3 (D13), SW4.2
enable: A1.9 (~ENABLE), A3.9 (~ENABLE), A4.9 (~ENABLE), ESP32 WROOM 32D DEVKIT1.4 (D12)
potentiometer: ESP32 WROOM 32D DEVKIT1.25 (D16), RV1.2

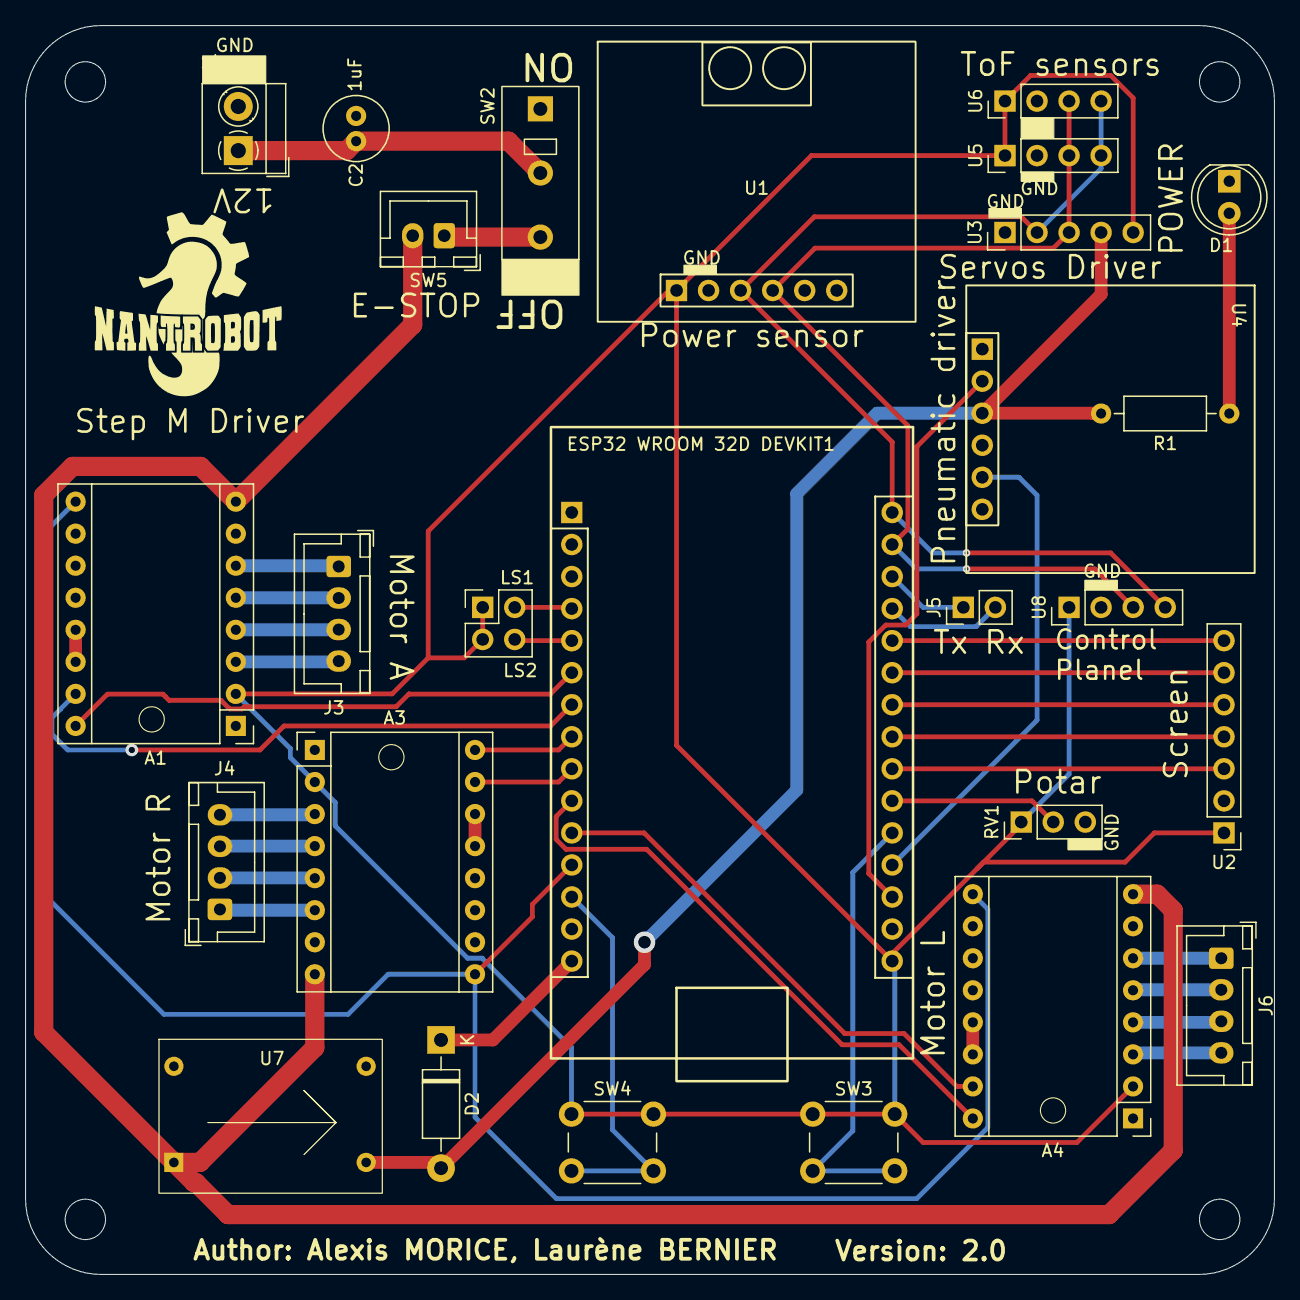
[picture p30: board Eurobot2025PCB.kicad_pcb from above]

Board: 2 copper layers, 99.0 x 99.0 mm, 31 parts (0 on the bottom side), 46 nets.

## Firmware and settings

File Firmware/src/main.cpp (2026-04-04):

#include <Arduino.h>
#include "config.h"
#include "robot.h"
#include "motorHandler.h"
#include "point.h"
// #include "displayHandler.h"
#include "powerSensorHandler.h"
#include "controlPanelHandler.h"
#include "debug.h"
#include "stacking.h"
#include "servoHandler.h"

#include <chrono>

#include "Wire.h"
#include <math.h>

SemaphoreHandle_t i2cMutex = xSemaphoreCreateMutex();

TwoWire myWire(0);
TwoWire wireDisplay(1);

using namespace ecn;

Robot robot(0, 0, 0, 3, 5, 0.01, 0.1); // x, y, theta, speed, kp, ki, kd

// DisplayHandler display;

// // Robot state (in meters, radians)
float currentX = 0.0;
float currentY = 0.0;
float currentTheta = 0.0;

// Timing
unsigned long lastUpdateTime = 0;
unsigned long startTime = 0;

// const int internalLed = 2; // eingebaute LED auf GPIO 2

float distance_to_goal = 0.0;

bool emergencystop = false;
int emergency_counter = 0;

bool start_timer = false;
auto start_time = std::chrono::steady_clock::now();

enum RobotState
{
    WAIT,
    INIT,
    NAVIGATION,
    TURN_TO_GOAL,
    TURN_TO_PATH,
    GOAL_REACHED,
    PATH_PLANNING
};
RobotState state = WAIT;
RobotState last_sent_state = WAIT;

String pathBuffer = ""; // Buffer to store the incoming path data

float distance_to_travel_4 = -27.0;

bool continue_after_straight = false;

int straight_counter = 0;
int go_back_counter_limit = 20;

float max_straight_speed = 10.0; // Maximum speed for straight movement
float straight_speed = 0.0;      // Current speed for straight movement

void sendpath(const std::vector<Point> &path)
{
    Serial.print("PATH:");
    for (size_t i = 0; i < path.size(); ++i)
    {
        Serial.printf("%f,%f", path[i].x, path[i].y);
        if (i < path.size() - 1)
        {
            Serial.print(";"); // Separate points with semicolons
        }
    }
    Serial.print("\n"); // End the path message
}

void parseGoals(String data)
{
    robot.goals.clear();
    int lastIndex = 0;
    while (lastIndex < data.length())
    {
        int nextIndex = data.indexOf(';', lastIndex);
        if (nextIndex == -1)
            nextIndex = data.length();

        String segment = data.substring(lastIndex, nextIndex);
        lastIndex = nextIndex + 1;

        int comma1 = segment.indexOf(',');
        int comma2 = segment.lastIndexOf(',');

        if (comma1 == -1 || comma2 == -1)
            continue;

        float x = segment.substring(0, comma1).toFloat();
        float y = segment.substring(comma1 + 1, comma2).toFloat();
        float theta = segment.substring(comma2 + 1).toFloat();

        robot.goals.push_back(Pose(x, y, theta * M_PI / 180));
    }

    robot.setPose(robot.goals[0].point.x, robot.goals[0].point.y, robot.goals[0].theta);

    // Initialize the robot's position with the first goal's coordinates
    if (xSemaphoreTake(robotXMutex, portMAX_DELAY) == pdTRUE)
    {
        _robotX = robot.goals[0].point.x;
        _robotY = robot.goals[0].point.y;
        _robotTheta = robot.goals[0].theta;
        xSemaphoreGive(robotXMutex);
    }

    robot.setTargetTheta(robot.goals[0].theta);

    Serial.print("Goals received: ");
    for (const auto &goal : robot.goals)
    {
        Serial.printf("(%f, %f, %f) ", goal.point.x, goal.point.y, goal.theta);
    }
    Serial.println();
}

// void parsePath(String data)
// {
//     robot.path_.clear();
//     int lastIndex = 0;
//     while (lastIndex < data.length())
//     {
//         int nextIndex = data.indexOf(';', lastIndex);
//         if (nextIndex == -1)
//             nextIndex = data.length();

//         String segment = data.substring(lastIndex, nextIndex);
//         lastIndex = nextIndex + 1;

//         int comma = segment.indexOf(',');
//         if (comma == -1)
//             continue;

//         float x = segment.substring(0, comma).toFloat();
//         float y = segment.substring(comma + 1).toFloat();
//         // Serial.printf("Parsedpath Point: (%f, %f)\n", x, y);
//         robot.path_.push_back(Point(x, y));
//     }
//     // Serial.print("Full Path received: ");
//     // for (const auto &point : robot.path_)
//     // {
//     //     Serial.printf("(%f, %f) ", point.x, point.y);
//     // }
//     // Serial.println();
//     Serial.print("Number of points in the path::: ");
//     Serial.println(robot.path_.size());
// }

// void moveStraightsimple(bool forward)
// {
//     if (straight_counter < max_straight_speed)
//     {
//         if (forward)
//             straight_speed += 1;
//         else
//             straight_speed -= 1;

//         robot.setWheelSpeed(straight_speed, straight_speed);
//     }
//     if (straight_counter > max_straight_speed && straight_counter < (go_back_counter_limit - max_straight_speed))
//     {
//         if (forward)
//             robot.setWheelSpeed(max_straight_speed, max_straight_speed);
//         else
//             robot.setWheelSpeed(-max_straight_speed, -max_straight_speed);
//     }
//     if (straight_counter >= (go_back_counter_limit - max_straight_speed) && straight_counter < go_back_counter_limit)
//     {
//         if (forward)
//             straight_speed -= 1;
//         else
//             straight_speed += 1;

//         robot.setWheelSpeed(straight_speed, straight_speed);
//     }

//     straight_counter++;

//     if (straight_counter >= go_back_counter_limit)
//     {
//         straight_speed = 0;
//         robot.setWheelSpeed(straight_speed, straight_speed);
//         straight_counter = 0;
//         continue_after_straight = true;
//     }
// }

void parseSpeedAndPID(String data)
{
    int firstComma = data.indexOf(',');
    int secondComma = data.indexOf(',', firstComma + 1);
    int thirdComma = data.indexOf(',', secondComma + 1);

    if (firstComma == -1 || secondComma == -1 || thirdComma == -1)
        return;

    float speed = data.substring(0, firstComma).toFloat();
    float P = data.substring(firstComma + 1, secondComma).toFloat();
    float I = data.substring(secondComma + 1, thirdComma).toFloat();
    float D = data.substring(thirdComma + 1).toFloat();

    robot.setSpeed(speed);
    robot.setPID(P, I, D);

    Serial.print("Received Speed and PID: ");
    Serial.print("Speed: ");
    Serial.print(speed);
    Serial.print(", P: ");
    Serial.print(P);
    Serial.print(", I: ");
    Serial.print(I);
    Serial.print(", D: ");
    Serial.println(D);
}

void processCommand(String command)
{
    // Serial.println("RCCCC: " + command);

    if (command.startsWith("GOALS:"))
    {
        parseGoals(command.substring(6));
        Serial.println("ACK:GOALS_RECEIVED");

        state = INIT;
    }

    // else if (command.startsWith("PATH:"))
    // {
    //     pathBuffer += command.substring(5);
    // }

    // else if (command.startsWith("PT:")){
    //     pathBuffer += command.substring(3);
    // }

    // else if (command.startsWith("PATHEND:"))
    // {
    //     pathBuffer += command.substring(8);
    //     parsePath(pathBuffer);
    //     pathBuffer = "";
    //     Serial.println("ACK:PATH_RECEIVED");

    // }

    else if (command.startsWith("STATE:"))
    {
        // String stateStr = command.substring(6);
        // // if (stateStr == "INIT")
        // //     state = INIT;
        // // else if (stateStr == "NAVIGATION")
        // //     state = NAVIGATION;
        // // else if (stateStr == "TURN_TO_GOAL")
        // //     state = TURN_TO_GOAL;
        // // else if (stateStr == "TURN_TO_PATH")
        // //     state = TURN_TO_PATH;
        // // else if (stateStr == "GOAL_REACHED")
        // //     state = GOAL_REACHED;
        // Serial.print("ACK:STATE_RECEIVED:_");
        // Serial.print(stateStr);
        // Serial.println("_");
    }

    if (command == "EMERGENCYSTOP")
    {
        emergencystop = true;
        Serial.println("EMERGENCYSTOP_RECEIVED");
    }
    // else if (command == "RESET")
    // {
    //     Serial.println("ESP32 restarting...");
    //     ESP.restart(); // Software Reset
    // }

    else if (command.startsWith("SPEED_PID:"))
    {
        parseSpeedAndPID(command.substring(10));
    }
}

void sendPositionUpdate()
{
    if (xSemaphoreTake(robotXMutex, portMAX_DELAY) == pdTRUE)
    {
        robot.setPose(_robotX, _robotY, _robotTheta);
        xSemaphoreGive(robotXMutex);

        // digitalWrite(internalLed, HIGH);
        Serial.print("X: ");
        Serial.print(robot.getX());
        Serial.print(", Y: ");
        Serial.print(robot.getY());
        Serial.print(", Theta: ");
        Serial.println(robot.getTheta());
        // digitalWrite(internalLed, LOW);
    }
}

void setServos(int degrees)
{
    for (int i = 0; i < 16; i++)
    {
        setServo(i, degrees);
        delay(10);
    }
}

void setup()
{
    Serial.begin(921600);
    while (!Serial)
    {
        delay(10);
    }
    delay(200);

    Serial.println("");
    Serial.print("RESET!\n");
    Serial.println("");

    SerialTitle("Initialisation du système");

    SerialInfo("1/6 Initialisation de la pompe...");
    // initPump();

    SerialInfo("2/6 Initialisation du servo...");
    initServo();

    SerialInfo("3/6 Initialisation du capteur de puissance...");
    // initPowerSensor();

    SerialInfo("4/6 Initialisation du moteur...");
    initMotor();

    SerialInfo("5/6 Initialisation de l'afficheur...");
    // display.initDisplay(true, false);

    SerialInfo("6/6 Initialisation de l'afficheur...");
    // initControlPanel();

    SerialInfo("Initialisation terminée avec succès !");

    setMotorSpeeds(0, 0);

    setServos(0);
    vTaskDelay(600); // Hold position
    setServos(70);
    vTaskDelay(600); // Hold position
    setServos(0);

    // pinMode(internalLed, OUTPUT);
    // digitalWrite(internalLed, LOW);

    // Reset timer for control loop
    lastUpdateTime = millis();
    startTime = millis();

    // testServo();

    pinMode(starter_button, INPUT_PULLDOWN);
    pinMode(colour_button, INPUT_PULLDOWN);
    pinMode(save_start_button, INPUT_PULLDOWN);

    // while(true)
    //  {
    //     Serial.print(digitalRead(starter_button));
    //     Serial.print(", ");
    //     Serial.print(digitalRead(colour_button));
    //     Serial.print(", ");
    //     Serial.println(digitalRead(save_start_button));
    //  }

    while (digitalRead(save_start_button) == LOW)
    {
        Serial.print("Waiting for Save Start button...\n");
        vTaskDelay(200);
    }

    Serial.println("security button pressed, waiting for Start button...");

    while (digitalRead(starter_button) == HIGH)
    {
        Serial.println("Waiting for Start button to be pressed...");
        vTaskDelay(200);
    }

    Serial.println("ESP Initialized!");

    Serial.print("START!\n");

    if (digitalRead(colour_button) == LOW)
    {
        Serial.print("COLOUR:yellow\n");
    }
    else
    {
        Serial.print("COLOUR:blue\n");
    }
}

RobotState lastState = GOAL_REACHED; // Letzter ausgegebener Zustand

void loop()
{
    if (millis() - lastUpdateTime >= robot.getDtInMs())
    {
        lastUpdateTime = millis();

        if (emergencystop == true)
        {
            emergency_counter++;
            if (emergency_counter > 65)
            {
                emergencystop = false;
                emergency_counter = 0;
            }
        }

        while (Serial.available())
        {
            String command = Serial.readStringUntil('\n');
            processCommand(command);

            // // If a PATH message is received, wait until PATHEND message
            // if (command.startsWith("PATH:"))
            // {
            //     // Collect all parts of the path until we encounter PATHEND
            //     String fullPath = ""; // Initialize empty string to store the full path

            //     if (command.startsWith("PATH:"))
            //     {
            //         command = command.substring(5); // Remove "PATH:" prefix
            //     }

            //     fullPath += command;
            //     int counter = 0;
            //     // Keep collecting until "PATHEND:" is found
            //     while (true)
            //     {
            //         if (Serial.available())
            //         {
            //             command = Serial.readStringUntil('\n');
            //             // Serial.println("RCCCC: " + command);

            //             // counter++;
            //             // Serial.print("Received Path Count: ");
            //             // Serial.println(counter);

            //             // If we encounter "PATHEND:", we need to remove it before adding to fullPath
            //             if (command.startsWith("PATHEND:"))
            //             {
            //                 command = command.substring(8); // Remove "PATHEND:" prefix
            //                 fullPath += command;            // Add the final chunk to the full path
            //                 parsePath(fullPath);       // Process the complete path
            //                 break;                          // Exit the loop after processing
            //             }
            //             else
            //             {
            //                 // Otherwise, just add the chunk to the full path
            //                 fullPath += command.substring(3);
            //             }
            //         }
            //     }
            // }
        }

        // static String inputString = ""; // Buffer for incoming data

        // while (Serial.available())
        // {
        //     char c = Serial.read();
        //     inputString += c;

        //     if (c == '\n')
        //     { // Full message received
        //         processCommand(inputString);
        //         inputString = ""; // Reset buffer
        //     }
        // }

        switch (state)
        {
        case WAIT:

            while (Serial.available())
            {
                String command = Serial.readStringUntil('\n');
                processCommand(command);
            }

            Serial.print("CurrentState: WAIT\n");

            break;
        case INIT:
            Serial.println("CurrentState: INIT");

            Serial.printf("Current Goal: %f, %f, %f\n", robot.goals[robot.getCurrentGoalindex()].point.x, robot.goals[robot.getCurrentGoalindex()].point.y, robot.goals[robot.getCurrentGoalindex()].theta);

            robot.setIsStarting(true);

            if (start_timer)
            {
                start_time = std::chrono::steady_clock::now();
            }

            robot.generateStraightPath();

            sendpath(robot.getPath());

            state = TURN_TO_PATH;
            [[fallthrough]];

        case TURN_TO_PATH:
            Serial.println("CurrentState: TURN_TO_PATH");

            if (INIT != last_sent_state)
            {
                Serial.print("STATE:INIT\n");
                last_sent_state = INIT;
            }

            if (robot.turnToPathOrientation())
            {
                Serial.println("Robot is aligned to path orientation!");
                robot.setIsStarting(true);
                robot.start_turning = true;
                state = NAVIGATION;
            }

            break;

        case NAVIGATION:
            if (PATH_PLANNING != last_sent_state)
            {
                Serial.print("STATE:PATH_PLANNING\n");
                last_sent_state = PATH_PLANNING;
            }
            Serial.println("CurrentState: NAVIGATION");

            robot.followPath();

            // float start = Point(robot.getX(), robot.getY());
            distance_to_goal = robot.distanceToGoal(robot.goals[robot.getCurrentGoalindex()].point);
            if (distance_to_goal < 5.0)
            {
                // std::cout << "Distance to goal: " << distance_to_goal << std::endl;

                if (distance_to_goal < 0.5)
                {
                    Serial.printf("Goal reached: %f, %f, %f\n", robot.goals[robot.getCurrentGoalindex()].point.x, robot.goals[robot.getCurrentGoalindex()].point.y, robot.goals[robot.getCurrentGoalindex()].theta);
                    std::cout << "Robot has reached the goal -> TURN_TO_GOAL!" << std::endl;
                    state = TURN_TO_GOAL;
                }
            }

            break;

        case TURN_TO_GOAL:
            Serial.println("CurrentState: TURN_TO_GOAL");
            Serial.print("STATE:TURN_TO_GOAL\n");

            if (last_sent_state != WAIT)
            {
                Serial.print("STATE:WAIT\n");
                last_sent_state = WAIT;
                // delay(1000);
            }

            if (robot.turnToGoalOrientation())
            {
                std::cout << "Robot is aligned to goal orientation!" << std::endl;
                robot.start_turning = true;
                state = GOAL_REACHED;
            }

            break;

        case GOAL_REACHED:

            Serial.println("CurrentState: GOAL_REACHED");
            Serial.print("STATE:GOAL_REACHED\n");
            Serial.print("current_goal_index: ");
            Serial.println(robot.getCurrentGoalindex());

            vTaskDelay(200);

            if (robot.getCurrentGoalindex() < robot.goals.size() - 1)
            {

                if (robot.getCurrentGoalindex() == 2)
                {

                        setServos(70);
                        vTaskDelay(500);

                        Serial.println("Robot is aligned to path orientation!");
                        robot.setIsStarting(true);
                        robot.start_turning = true;
                        robot.incrementCurrentGoalIndex();
                        Serial.print("New current_goal_index: ");
                        Serial.println(robot.getCurrentGoalindex());
                        Serial.printf("New Goal: %f, %f, %f\n", robot.goals[robot.getCurrentGoalindex()].point.x, robot.goals[robot.getCurrentGoalindex()].point.y, robot.goals[robot.getCurrentGoalindex()].theta);
                        robot.setTargetTheta(robot.goals[robot.getCurrentGoalindex()].theta);
                        std::cout << "Set Target theta to: " << robot.goals[robot.getCurrentGoalindex()].theta << std::endl;

                        continue_after_straight = false;

                        state = INIT;
                }
                if (robot.getCurrentGoalindex() == 7)
                {

                    setServos(70);
                    vTaskDelay(500);

                    Serial.println("Robot is aligned to path orientation!");
                    robot.setIsStarting(true);
                    robot.start_turning = true;
                    robot.incrementCurrentGoalIndex();
                    Serial.print("New current_goal_index: ");
                    Serial.println(robot.getCurrentGoalindex());
                    Serial.printf("New Goal: %f, %f, %f\n", robot.goals[robot.getCurrentGoalindex()].point.x, robot.goals[robot.getCurrentGoalindex()].point.y, robot.goals[robot.getCurrentGoalindex()].theta);
                    robot.setTargetTheta(robot.goals[robot.getCurrentGoalindex()].theta);
                    std::cout << "Set Target theta to: " << robot.goals[robot.getCurrentGoalindex()].theta << std::endl;

                    continue_after_straight = false;

                    state = INIT;
                }

                if (robot.getCurrentGoalindex() == 4) // without start so real goal
                {
                    if (straight_counter == 0)
                    {
                        setServos(0);
                        vTaskDelay(500);
                    }
                    // moveStraightsimple(false);
                    if (straight_counter < go_back_counter_limit)
                    {
                        robot.setWheelSpeed(-5.0, -5.0);

                        straight_counter++;
                    }
                    if (straight_counter >= go_back_counter_limit)
                    {
                        robot.setWheelSpeed(0, 0);
                        straight_counter = 0;
                        continue_after_straight = true;
                    }
                    if (continue_after_straight == true)
                    {
                        Serial.println("Robot is aligned to path orientation!");
                        robot.setIsStarting(true);
                        robot.start_turning = true;
                        robot.incrementCurrentGoalIndex();
                        Serial.print("New current_goal_index: ");
                        Serial.println(robot.getCurrentGoalindex());
                        Serial.printf("New Goal: %f, %f, %f\n", robot.goals[robot.getCurrentGoalindex()].point.x, robot.goals[robot.getCurrentGoalindex()].point.y, robot.goals[robot.getCurrentGoalindex()].theta);
                        robot.setTargetTheta(robot.goals[robot.getCurrentGoalindex()].theta);
                        std::cout << "Set Target theta to: " << robot.goals[robot.getCurrentGoalindex()].theta << std::endl;

                        continue_after_straight = false;

                        state = INIT;
                    }
                }
                if (robot.getCurrentGoalindex() == 8) // without start so real goal
                {
                    if (straight_counter == 0)
                    {
                        setServos(0);
                        vTaskDelay(500);
                    }
                    // moveSt
                    // moveStraightsimple(false);
                    if (straight_counter < go_back_counter_limit)
                    {
                        robot.setWheelSpeed(-5.0, -5.0);
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

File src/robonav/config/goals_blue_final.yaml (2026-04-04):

robot:
  wheel_distance: 37.3
  speed: 30.0
  pid:
    kp: 28
    ki: 0.02
    kd: 0.6


# TEAM BLUE STRATEGY
# start at goal 22
# goal 29 - pick up cans
# goal 22 - drop off cans
# goal 33 - pick up cans -- handle differently by esp 
# (goal 24 - drop off cans -- reached by esp) 
# goal 35 - pick up cans
# goal 23 - drop off cans
# goal 18 - final position

goals:
    # Step = 0
    # Starting Position (Goal #22)  
  - x: 177
    y: 184
    theta: -90

  #   # Step = 1
  #   # Goal 23   midpoint
  # - x: 177
  #   y: 154
  #   theta: -90

  # Step = 1
  # Goal 29
  - x: 190
    y: 133
    theta: -90

  # Step = 2
  # Goal PICK UP CANS (from 29)
  - x: 190
    y: 112
    theta: -90

  # Step = 3
    # Goal 23   midpoint
  - x: 177
    y: 154
    theta: 90

    # Step = 4
    # Goal 22   (DROP OFF CANS)
  - x: 177
    y: 175
    theta: 90

    # Step = 5
    # Goal 23   midpoint
  - x: 177
    y: 154
    theta: -15

    # Step = 6
    # Goal 33    
  - x: 222
    y: 145
    theta: 90

    # Step = 7
    # Goal 33    PICK UP CANS (from 33)
  - x: 222
    y: 171
    theta: 90

    # Step = 8
    # Goal 24     (DROP OFF CANS)
  - x: 222
    y: 184
    theta: 90

    # MOVE BACKWARDS A LITTLE BIT (esp)

  # # Step = 9
  #   # Goal 35
  # - x: 217
  #   y: 65
  #   theta: -90

  #   # Step = 10
  #   # PICK UP CANS (from 35)
  # - x: 217
  #   y: 31
  #   theta: -90

  #   # MOVE BACKWARDS A LITTLE BIT MORE (esp)

  #   # Step = 11
  #   # Goal 23  (DROP OFF CANS)
  # - x: 177
  #   y: 154
  #   theta: 90

    # Step = 12
    # Goal 30  midpoint
  - x: 245
    y: 75
    theta: -25

    # Step = 13
    # Goal 18
  - x: 262
    y: 25
    theta: -90

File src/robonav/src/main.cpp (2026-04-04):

// #include <a_star.h>
#include <chrono>
#include <cstdlib>
#include <ctime>
// #include <elastic_bands.h>
#include <filesystem>
#include <fstream>
#include <iomanip> // For std::fixed and std::setprecision
#include <iostream>
#include <maze.h>
#include <point.h>
#include <position.h>
#include <sstream>         // For std::ostringstream
#include <yaml-cpp/yaml.h> // Include the YAML library

#include "point.h"
#include "robot.h"

#include "geometry_msgs/msg/point_stamped.hpp"
#include "geometry_msgs/msg/twist.hpp"
#include "nav_msgs/msg/odometry.hpp"
#include "nav_msgs/msg/path.hpp"
#include "rclcpp/rclcpp.hpp"
#include "tf2_ros/buffer.h"
#include "tf2_ros/transform_listener.h"
#include <serial/serial.h>

#include <cv_bridge/cv_bridge.h>
#include <nav_msgs/msg/occupancy_grid.hpp>
// #include <sensor_msgs/msg/image.hpp>
#include <tf2_ros/transform_broadcaster.h>
#include <vector>
#include <visualization_msgs/msg/marker.hpp>

#include "std_msgs/msg/float64.hpp"
#include <csignal>
#include <vector>

#include "geometry_msgs/msg/pose_with_covariance_stamped.hpp"
#include "sensor_msgs/msg/point_cloud2.hpp"
#include <pcl/common/transforms.h>
#include <pcl/point_cloud.h>
#include <pcl/point_types.h>
#include <pcl/search/kdtree.h>
#include <pcl/segmentation/extract_clusters.h>
#include <pcl_conversions/pcl_conversions.h>
// #include <pcl_ros/transforms.hpp> // Provides pcl_ros::transformPointCloud

#include "geometry_msgs/msg/pose_array.hpp"

#include "led_control.h"

using namespace std;
using namespace ecn;

// enum RobotState { WAITING, INIT, PATH_PLANNING, NAVIGATION, TURN_TO_GOAL, TURN_TO_PATH, GOAL_REACHED };
enum RobotState { WAITING, INIT, PATH_PLANNING, NAVIGATION, GOAL_REACHED };

RobotState state = INIT;

Robot robot(Point::maze, 0, 0, 0, 18.5, 8, 25, 0.01, 0.5); // Maze, initial position (x, y, theta), wheelbase, speed in cm/s, P, I, D

double robot_x = 0.0, robot_y = 0.0, robot_theta = 0.0;

bool team_colour = 0;

ecn::Point pop;

bool emergencystate             = false;

int sendpathcounter = 0;

std::vector<ecn::Point> received_path;

LEDControl led;

// gpiod::chip gpio("gpiochip0"); // Öffnet direkt den ersten GPIO-Chipauto 
// gpiod::line led_pin = gpio.get_line(24);


void processPointCloud(const sensor_msgs::msg::PointCloud2::SharedPtr& cloud_msg,
                       Maze& maze,
                       float robot_pos_x,
                       float robot_pos_y,
                       const rclcpp::Publisher<sensor_msgs::msg::PointCloud2>::SharedPtr& cloud_publisher,
                       const rclcpp::Publisher<sensor_msgs::msg::PointCloud2>::SharedPtr& cloud_notused_publisher,
                       const rclcpp::Publisher<sensor_msgs::msg::PointCloud2>::SharedPtr& cloud_tooclose_publisher,
                       const rclcpp::Node::SharedPtr& node)
{
    robot_pos_x               = robot_x / 100.0;
    robot_pos_y               = 2 - (robot_y / 100.0);
    float reduction           = 0.25;
    float min_x               = 0 + reduction;
    float max_x               = 3 - reduction;
    float min_y               = 0 + reduction;
    float max_y               = 2 - reduction;
    float radius_around_robot = 0.3; // Radius around the robot to exclude points for putting obstacles on the map

    float close_obstacle_threshold = 0.40;


    // Convert PointCloud2 to PCL PointCloud
    pcl::PointCloud<pcl::PointXYZ>::Ptr cloud(new pcl::PointCloud<pcl::PointXYZ>());
    pcl::fromROSMsg(*cloud_msg, *cloud);

    int count_close_points = 0;

    // Filter points within the desired map area and exclude points within a radius of 30cm from the robot
    pcl::PointCloud<pcl::PointXYZRGB>::Ptr cloud_filtered(new pcl::PointCloud<pcl::PointXYZRGB>());
    pcl::PointCloud<pcl::PointXYZRGB>::Ptr cloud_filtered_notused(new pcl::PointCloud<pcl::PointXYZRGB>());
    pcl::PointCloud<pcl::PointXYZRGB>::Ptr cloud_filtered_tooclose(new pcl::PointCloud<pcl::PointXYZRGB>());
    for (const auto& pt : cloud->points) {
        float distance_to_robot = std::sqrt(std::pow(pt.x - robot_pos_x, 2) + std::pow(pt.y - robot_pos_y, 2));
        if (pt.x >= min_x && pt.x <= max_x && pt.y >= min_y && pt.y <= max_y && distance_to_robot > radius_around_robot) {
            pcl::PointXYZRGB colored_pt;
            colored_pt.x = pt.x;
            colored_pt.y = pt.y;
            colored_pt.z = pt.z;
            colored_pt.r = 255;
            colored_pt.g = 255;
            colored_pt.b = 255;
            cloud_filtered->points.push_back(colored_pt);
        } else {
            pcl::PointXYZRGB colored_pt_notused;
            colored_pt_notused.x = pt.x;
            colored_pt_notused.y = pt.y;
            colored_pt_notused.z = pt.z;
            colored_pt_notused.r = 50;
            colored_pt_notused.g = 50;
            colored_pt_notused.b = 50;
            cloud_filtered_notused->points.push_back(colored_pt_notused);
        }
        
        if (distance_to_robot <= close_obstacle_threshold) {
            pcl::PointXYZRGB colored_pt_tooclose;
            colored_pt_tooclose.x = pt.x;
            colored_pt_tooclose.y = pt.y;
            colored_pt_tooclose.z = pt.z;
            colored_pt_tooclose.r = 255;
            colored_pt_tooclose.g = 50;
            colored_pt_tooclose.b = 50;
            cloud_filtered_tooclose->points.push_back(colored_pt_tooclose);

            count_close_points++;
        }
        
    }

    emergencystate = false;

    if (count_close_points > 0) {
        emergencystate = true;
        std::cout << "⚠️ Emergency state activated! Close points detected: " << count_close_points << std::endl;
    } else {
        emergencystate = false;
    }

    // Perform clustering
    maze.resetIm(); // Reset the maze before processing new points

    pcl::search::KdTree<pcl::PointXYZRGB>::Ptr tree(new pcl::search::KdTree<pcl::PointXYZRGB>());
    tree->setInputCloud(cloud_filtered);

    std::vector<pcl::PointIndices> cluster_indices;
    pcl::EuclideanClusterExtraction<pcl::PointXYZRGB> ec;
    ec.setClusterTolerance(0.1); // minimum distance of points in a cluster
    ec.setMinClusterSize(3);     // Minimum number of points in a cluster
    ec.setMaxClusterSize(80);
    ec.setSearchMethod(tree);
    ec.setInputCloud(cloud_filtered);
    ec.extract(cluster_indices);

    maze.resetIm(); // Reset the maze before processing new clusters

    // Map to store smoothed centers for each cluster
    static std::unordered_map<int, std::pair<float, float>> smoothed_centers;
    static bool first_time = true;
    const float alpha      = 0.85; // Smoothing factor (0 < alpha < 1) higher is less smoothing

    // Process each cluster
    int cluster_id = 0;
    for (const auto& indices : cluster_indices) {
        float sum_x = 0.0, sum_y = 0.0;
        for (const auto& idx : indices.indices) {
            const auto& pt = cloud_filtered->points[idx];
            sum_x += pt.x;
            sum_y += pt.y;
        }
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

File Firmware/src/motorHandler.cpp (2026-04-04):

#include "robot.h"
#include <math.h>
#include "motorHandler.h"
#include "servoHandler.h"
#include <AccelStepper.h>
#include "config.h"
#include "debug.h"
#include "servoHandler.h"
SemaphoreHandle_t robotXMutex;

// extern Robot robot;

volatile float robotX = 0.0;
volatile float robotY = 0.0;
volatile float robotTheta = 0.0;
volatile float _robotX = 0.0;
volatile float _robotY = 0.0;
volatile float _robotTheta = 0.0;

const double oneStepAngle = 2.0 * M_PI / stepsPerRevolution;   // [rad]
const double metersPerStep = oneStepAngle * wheelDiameter / 2; // [m]
// １m/s = 1 / metersPerStep [steps/s]

// Create motor instances
AccelStepper motorR(motorInterfaceType, stepPin2, dirPin2);
AccelStepper motorL(motorInterfaceType, stepPin1, dirPin1);
AccelStepper motorX(motorInterfaceType, stepPinX, dirPinX);

int end_X_sensor = LOW;

void initMotor()
{
    // Set maximum speed and acceleration
    motorL.setMaxSpeed(20000);
    motorL.setAcceleration(5000);

    motorR.setMaxSpeed(20000);
    motorR.setAcceleration(5000);

    // Invert direction if needed
    motorR.setPinsInverted(true, false, false);

    motorL.setCurrentPosition(0);
    motorR.setCurrentPosition(0);

    // Create the mutex before starting the task.
    robotXMutex = xSemaphoreCreateMutex();
    if (robotXMutex == NULL)
    {
        Serial.println("Failed to create mutex!");
    }

    xTaskCreatePinnedToCore(
        allRunSpeed,   // Task function
        "allRunSpeed", // Name
        2048,          // Stack size
        NULL,          // Parameters
        1,             // Lower priority (instead of a high value)
        NULL,          // Task handle
        1              // CPU core (1)
    );

    disableCore1WDT();

    Serial.println("Motors initialized!");
}
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

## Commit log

2024-11-06 Code and schematics for testing the stepper motor
    [schematics esp32 2xNema17.fzz]
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2024-12-02 EB: fixed endpoints, use old a*path if it exist, better displaying
    [elastic_bands.h]
2024-12-04 Update localization.h
    added function to compute motor angle needed to reach the target position
2024-12-04 Update test.cpp
    updated test code to test new function that computes the motor angles required to reach a target position
2024-12-04 Update localization.cpp
    Added the implementation of the function that computes the motor angles required to reach the target position
2024-12-05 EB with float position and commented out debbuging codelines for one circle. Sometimes points stuck becuase displacement to big because of repulsion force. New interactive map generator, not 100% wor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
    [elastic_bands.h]
2024-12-05 interactive maze generator working, but a* of that maze not finding correct goal
    [elastic_bands.h]
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2024-12-08 eb working well, obstacle class added, problem with narrow passages, number of pathpoints at beginning and end nnot working very well, and symmetrical abstacles also not
    [elastic_bands.h, main.cpp]
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2024-12-12 a star working with downsized image, elastic band improved, smoothing bug imporved
    [elastic_bands.h, main.cpp]
2024-12-16 added proximity moving obstacle sesor, turn to path, vizulisation of sensor and transparent eb ...
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2024-12-19 Update localization.cpp
    added followPath function. The 3 functions updatePose, computeWheelAngles and followPath will be added in the arduino code of the Esp32 to control the motor with the number of steps to turn.
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2025-01-29 Banner V1
    [BATTERY_12V_PARKSIDE_2Ah.SLDPRT, BEARING.SLDPRT, BRACKET.STL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]
2025-01-29 Added missing motorHandler.h file
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2025-02-06 CAD for first version of battery holder
    [BATTERY_12V_PARKSIDE_2Ah.SLDPRT, BATTERY_ASSEMBLY.SLDASM, BATTERY_ASSEMBLY2.SLDASM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]
2025-02-08 rviz and gazebo
    [inertial_macros.xacro, robot.urdf.xacro, robot_core.xacro]
2025-02-08 robot is in rviz and gazebo in playmat and can be controlled by keyboard
    [column.sdf, column_.stl, gazebo_control.xacro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]
2025-02-10 CAD parts for stacking mecanism
    [ROUND_LINEAR_BEARING.SLDPRT, ROUND_LINEAR_GUIDE.SLDPRT, ROUND_LINEAR_SLIDE.SLDASM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]
2025-02-10 robot moving
    [column.sdf, column_.stl, gazebo_control.xacro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]
2025-02-10 sned /cmd_vel from main
    [inertial_macros.xacro, robot.urdf.xacro, robot_core.xacro]
2025-02-11 robot pathfollowing and simple world gazebo, path in rviz
    [Eurobot_map_real_bw_10_p_rviz.yaml, robot_core.xacro]
2025-02-12 Updated Moving Frame.
    PLEASE NOTE: The mounting holes for the limit switch (10t85) need to be verified with below datasheet and real part. (https://www.chinadaier.com/wp-content/uploads/2017/08/Micro-switch.pdf)
    [AAbattery_holder.SLDPRT, MOVING_FRAME.SLDPRT]
2025-02-13 removed dt, dt = real execution time, improved some things, but still different in gazbeo
    [gazebo_control.xacro, robot_core.xacro]
2025-02-22 Add kicad pcb project
    [A4988-Stepper-Driver-Socketed.stp, Eurobot2025PCB.kicad_pcb, Eurobot2025PCB.kicad_sch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]
2025-02-25 CAD for pneumatic actuator
    [AIR_VALVE.SLDPRT, PNEUMATIC_ACTUATOR.SLDASM, PUMP.SLDPRT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]
2025-02-26 ajout pièce support pompe (axe x)
    [support_pompe.SLDPRT]
2025-02-26 adding pump support
    adding pump support
    [ROUND_LINEAR_SLIDE.SLDASM, SERVOMOTOR.SLDPRT]
2025-02-26 add z axis and corrections for x axis
    [support_axe_x.SLDPRT, support_pompe.SLDPRT]
2025-03-01 Add 4th step motor and 12V to 5V converter to PCB
    [Eurobot2025PCB.kicad_sch]
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2025-03-09 working better but robot is moving wrong
    [main.cpp]
2025-03-09 working better but robot is moving wrong 2
    [main.cpp, motorHandler.cpp]
2025-03-09 brouillon pour l'axe Z qui porte l'axe X
    [axe_2.SLDPRT]
2025-03-10 Updated front actuator (=first one printed)
    [FRONT_ACTUATOR.SLDPRT, FRONT_ACTUATOR_TEST_FIT.SLDASM, Limit Switch.STEP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]
2025-03-10 updated some of the CAD
    [AIR_VALVE.SLDPRT, MAGNET_HOLDER.STL, MOVING_FRAME.SLDPRT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]
2025-03-12 updated CAD
    [FRONT_ACTUATOR_TEST_FIT.SLDASM, TEST_X_AXIS.SLDPRT, TEST_X_AXIS.STL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]
2025-03-13 communication working, esp driving wrong 1
    [main.cpp]
2025-03-13 communication working, esp driving wrong 2
    [main.cpp, robot.h]
2025-03-13 rviz vizualization, but robot model not moving and robot moving weird, path sending is taking long
    [robot.urdf.xacro, robot_core.xacro]
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2025-03-18 Reorganised CAD folder
    Moved all standard parts to a separate folder
    Change naming convention : ALL_CAPITAL for standard parts and Snake_case for custom made parts
    [AAbattery_holder.SLDPRT, AIR_VALVE.SLDPRT, Axe_X(old).SLDPRT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]
2025-03-19 working fine exept path sending and PID
    [robot_core.xacro]
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2025-03-19 updated pcb
    [Eurobot2025PCB.kicad_sch]
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2025-03-19 ajout base axe Z
    [Axe_X.SLDPRT, Base_axe_z.SLDPRT, FRONT_ACTUATOR.SLDPRT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]
2025-03-19 supp temp
    [FRONT_ACTUATOR_TEST_FIT.SLDASM]
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2025-03-20 added map to rviz but not correct
    [main.cpp]
2025-03-20 Path following and communication with RPI and RSP working! Also vizualization in RVIZ
    [robot_core.xacro]
2025-03-26 CAD robot V1
    [Arm1.SLDPRT, Arm2.SLDPRT, Axe_X.SLDPRT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]
2025-03-26 FRONT actuator side
    [FRONT_ACTUATOR_SIDE.SLDPRT, FRONT_ACTUATOR_SIDE.STL, SQUARE_LINEAR_SLIDE.SLDASM]
2025-03-26 Robot driving and turning correctly to goalsgit status! (Band ath little zigzag but I dont know why
    [main.cpp, robot.cpp, robot.h]
2025-04-01 removed uneccecary stuff from rpi, fixed slow down before goal, added slow down when starting turning (not quite), display astar path (not quite) and elastic band circles
    [Eurobot_map_real_bw_10_p_rviz.yaml, column.sdf, column_.stl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]
2025-04-01 yaml file for params, slowing down/speeding up, vizualization in rviz, path sending time printed
2025-04-01 added big robot and tuned pid and settings
    [gazebo_control.xacro, robot.urdf.xacro, robot_core.xacro]
2025-04-03 lidar getting scan and rest almost wokring
    [robot.urdf.xacro, rplidar_c1.xacro]
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2025-04-26 update pcb :alien:
    [Eurobot2025PCB.kicad_pcb, Eurobot2025PCB.kicad_sch]
2025-05-15 meeting, obstacles on map but wrong, on /map_vis topic, wainting for esp
    [main.cpp]
2025-05-22 Lots of changes in CAD
    [Arm1.SLDPRT, Arm2.SLDPRT, Axe_X_V2.SLDPRT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]
2025-05-23 Obstacle Detection working, not yet moving, cleaned up files
    [BATTERY_12V_PARKSIDE_2Ah.SLDPRT, BEARING.SLDPRT, BRACKET.SLDPRT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]
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2025-05-24 changrd wheel distance to 37,6mm and made robot model good for rviz
    [materials.xacro, robot.urdf.xacro, robot_core.xacro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]
2025-05-24 added start from esp (rpi waits), added colour choosing almost, reset almost from esp, changed speed, wheel diameter
    [materials.xacro, rplidar_c1.xacro]
2025-05-24 added obstacles on the map, blue and yellow goals, lidar transform still not working
    [main.cpp]
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2025-05-26 rosbags, tf still not working, but the rest is
    [materials.xacro]
2025-05-28 working wiht lidar and my code 1.
    [rplidar_c1.xacro]
2025-05-28 compiling but esp error control panel
    [config.h, controlPanelHandler.cpp, main.cpp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]
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2025-05-29 pami firmware
    [ROUND_LINEAR_SLIDE.SLDASM, SQUARE_LINEAR_SLIDE.SLDASM, batterie externe.SLDPRT]
2025-05-29 working wiht straight paths, rviz vis, and pathplannung on esp and correct usb automatic on rpi
    [goals_yellow_final.yaml, main.cpp, robot.cpp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]
2025-05-30 one push working with simple backwards, sometimes jitter, better packwards not working
    [goals_blue_final.yaml, goals_yellow_final.yaml, main.cpp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]
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2025-05-30 NOW CORRECT, smal led mistake
    [main.cpp]
